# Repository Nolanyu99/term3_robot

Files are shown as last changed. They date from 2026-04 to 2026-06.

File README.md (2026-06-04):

# Term 3 Autonomous Robot

This repository contains the software, documentation, diagrams, and testing evidence for our Term 3 robotics challenge robot.

The final integrated robot software is an Arduino GIGA R1 WiFi project. It combines line following, IMU-based turning, RFID reading, MQTT/server communication, ultrasonic wall following, obstacle avoidance, arena pathfinding, return-to-base logic, emergency stop behaviour, revive behaviour, and seed dispensing.

---

## Final Viva/Test Run Version

The final code version used for the viva/test run is:

```text
Jason_combined_code/
```

The main file for the final integrated version is:

```text
Jason_combined_code/Main.ino
```

This folder is treated as the final assessed software version for the viva/test run.

Important note:

```text
All `.ino` files inside Jason_combined_code/ are part of the same Arduino sketch.
Do not upload Main.ino alone without the other tabs/files in the same folder.
```

---

## Final Code Folder Contents

| File | Purpose |
| --- | --- |
| `Main.ino` | Main integrated sketch. Defines configuration values, mission phases, global states, hardware pin assignments, tunnel logic, setup routine, calibration sequence, serial commands, stop/revive button handling, and the main mission state machine. |
| `ArenaTypes.h` | Shared type definitions used by the arena and revive logic, including `ArenaPoint`, `ArenaHeading`, `RFIDLocation`, and `Test8ReviveTarget`. |
| `ArenaPathfinding.ino` | Arena navigation and path planning. Uses an 11x11 planning grid around the 9x9 playable arena, decodes the 21-byte server map, uses weighted Dijkstra pathfinding, updates pose from RFID/server replies, marks temporary obstacles, and drives cell-by-cell toward a target. |
| `Messages.ino` | Non-blocking WiFi/MQTT communication layer. Handles WiFi reconnects, MQTT reconnects, topic building, incoming messages, map updates, fertility/location replies, revive broadcasts, emergency/disable messages, heartbeat/register messages, and server requests such as `isFertile`, `getMap`, `openAirlock`, and `reviveRequest`. |
| `IMU.ino` | IMU setup and gyro handling. Selects the best I2C bus, detects ADXL345, ITG320x, HMC5883L/QMC5883L, and BMP280, calibrates gyro Z-axis bias, integrates turn angle, and prints IMU status. |
| `LineSensors.ino` | 9-channel RC/QTR line sensor reading and calibration. Handles line detection, line position estimation, junction classification, line following, intersection crossing, gap recovery, and lost-line recovery. |
| `MotorEncoders.ino` | Motor and encoder support. Handles left/right encoder interrupts, encoder reads, Motoron setup, motor speed commands, stop commands, forward driving, proportional line-following motor correction, and centring after RFID/IR detection. |
| `ObstacleAvoid.ino` | Obstacle swerve state machine. Uses the forward ultrasonic sensor, line following without automatic junction turns, RFID-based junction detection, and scripted right/left turn sequence to move around an obstacle and return to the original trajectory. |
| `RFID.ino` | RFID reader setup and basic tag handling. Checks the RFID reader on I2C address `0x28`, validates firmware version, initialises the reader without soft reset, prints UID values, and triggers planting when a tag is detected in the simple RFID flow. |
| `RFIDServerTest.ino` | Manual and autonomous RFID/server helper. Provides `tryScanRFIDOnce()`, `scanRFIDAndQueryServer()`, and `runRFIDServerTest()`. The serial command `9` uses this to scan an RFID tag, send `isFertile`, wait for a server reply, and print UID, fertility, and x/y position. |
| `RobotBehaviour.ino` | Higher-level helper functions. Provides `plant()`, stop-input checking during blocking tests, and RFID scanning for test routines. Some older scripted test flows were removed because the arena pathfinder and server-based planting logic replaced them. |
| `Servos.ino` | Seed dispenser servo control. Converts angles to pulse widths, manually services servo pulses, closes both gates, and runs the upper/lower gate sequence to dispense one seed. |
| `Test8.ino` | Revive mission logic. Stores revive target broadcasts, selects a target, approaches using the forward ultrasonic sensor and line sensors if available, holds revive for 5 seconds, sends a revive request, then reverses until an RFID tag is found. |
| `Turning.ino` | IMU-based turning functions. Provides left/right 90-degree and 180-degree turns using gyro angle integration and line reacquisition, plus angle-only turning with timeout and stop-input checking. |
| `LEDs.ino` | RGB LED helper functions for red, green, yellow, blue, and flashing red status indication. |
| `Printing.ino` | Serial debug output. Prints line-following state, junction type, line position, motor commands, calibrated sensor values, IMU status, encoder counts, and calibration data. |

---

## Repository Structure

```text
term3_robot/
├── Jason_combined_code/       Final viva/test run Arduino sketch
├── Jason_wall_following_main/ Earlier wall-following version
├── Main/                      Earlier or alternative main code
├── Programming_Viva/          Earlier viva/programming modules
├── Test3/                     Older test code
├── Test8/                     Older or separate Test 8 code
├── Old/                       Archived code and older versions
├── cad/                       Mechanical CAD files and exports
├── docs/                      Documentation, planning material, datasheets, and test logs
├── include/                   Header files and shared definitions
├── src/                       PlatformIO source files and earlier application structure
├── platformio.ini             PlatformIO build configuration
├── RacetrackLineFollower.ino  Earlier line-following test code
└── README.md                  Repository guide
```

Only `Jason_combined_code/` should be treated as the final viva/test run version.

Other folders are kept for reference, diagnostics, earlier prototypes, or development history.

---

## Hardware Platform

The final code is designed for an Arduino GIGA R1 WiFi based differential-drive robot.

| Component | Purpose |
| --- | --- |
| Arduino GIGA R1 WiFi | Main microcontroller |
| Motoron motor controller | Controls the left and right drive motors |
| DC motors with encoders | Differential-drive movement and encoder feedback |
| 9-channel RC/QTR line sensor array | Line following, line recovery, and junction detection |
| IMU / gyro | Turn-angle estimation and IMU-based turning |
| RFID reader | Reads arena/base RFID tags |
| Forward ultrasonic sensor | Gate detection, obstacle detection, and revive approach distance |
| Side ultrasonic sensor | Tunnel wall-following distance measurement |
| Upper and lower servos | Seed dispenser gate mechanism |
| RGB LED | Robot status indication |
| Mechanical stop button | Pause / kill-switch behaviour |
| Revive button | Revive/contact trigger behaviour |
| WiFi/MQTT server link | Map, fertility, airlock, heartbeat, emergency, and revive communication |

---

## Important Pin and Address Configuration

The final configuration is defined mainly in `Main.ino`.

| Item | Configuration |
| --- | --- |
| Top RGB LED red | Pin `39` |
| Top RGB LED green | Pin `35` |
| Top RGB LED blue | Pin `37` |
| Mechanical stop button | Pin `33`, active low |
| Revive button | Pin `13`, active low |
| Line sensor pins | `2, 3, 4, 5, 8, 9, 10, 11, 12` |
| Left encoder | `A = 28`, `B = 26` |
| Right encoder | `A = 22`, `B = 24` |
| RFID reader | I2C address `0x28`, on `Wire1` |
| Motoron controller | I2C address `0x10`, on `Wire1` |
| Upper seed servo | Pin `36` |
| Lower seed servo | Pin `38` |
| Forward ultrasonic trigger/echo | Trigger `52`, echo `53` |
| Side ultrasonic trigger/echo | Trigger `47`, echo `46` |
| Serial baud rate | `115200` |

---

## Required Libraries

The final Arduino code uses these main libraries:

```cpp
#include <Arduino.h>
#include <Wire.h>
#include <Motoron.h>
#include <math.h>
#include <MFRC522_I2C.h>
#include "ArenaTypes.h"
```

The messaging layer also uses WiFi/MQTT-related Arduino networking functionality.

Before compiling, make sure the following are available in Arduino IDE or PlatformIO:

| Library / Dependency | Purpose |
| --- | --- |
| Arduino GIGA R1 board package | Arduino GIGA R1 WiFi support |
| `Wire` | I2C communication |
| `Motoron` | Motoron motor controller communication |
| `MFRC522_I2C` | RFID reader communication over I2C |
| Arduino WiFi / MQTT support | Server communication in `Messages.ino` |
| Arduino core libraries | General Arduino functions |

---

## Setup Steps

### 1. Clone or Download the Repository

```bash
git clone <repository-url>
```

Open the repository folder on your computer.

---

### 2. Open the Final Code

Open this file in Arduino IDE:

```text
Jason_combined_code/Main.ino
```

Arduino IDE should automatically load the other `.ino` files in `Jason_combined_code/` as tabs.

The final code depends on the full folder:

```text
Jason_combined_code/
```

Do not move `Main.ino` out of this folder unless all related `.ino` files and `ArenaTypes.h` are moved with it.

---

### 3. Select Board and Port

In Arduino IDE:

```text
Board: Arduino GIGA R1 WiFi
Port: Select the connected Arduino port
```

Use the M7 core if the IDE asks for the target core.

---

### 4. Install Required Libraries

Install the required external libraries through Arduino Library Manager or manually:

```text
Motoron
MFRC522_I2C
```

Also make sure the Arduino GIGA R1 WiFi board package and WiFi/MQTT dependencies are installed.

---

### 5. Check WiFi and Server Settings

The final code contains WiFi and MQTT/server settings for the robotics challenge environment.

Before uploading, check:

```text
WiFi SSID
WiFi password
MQTT broker address
Team ID
Board ID
Server board ID
Airlock/server message format
```

Security warning:

```text
Do not leave real WiFi credentials in a public GitHub repository.
```

If the repository is public, replace real credentials with placeholders, for example:

```cpp
constexpr const char* WIFI_SSID = "YOUR_WIFI_SSID";
constexpr const char* WIFI_PASSWORD = "YOUR_WIFI_PASSWORD";
```

Then document the real credentials privately for the team.

---

### 6. Upload the Code

Connect the Arduino GIGA R1 to the computer with a USB cable.

In Arduino IDE:

```text
Click Upload
```

After uploading, open Serial Monitor at:

```text
115200 baud
```

---

## How to Run the Robot

1. Place the robot at the correct start position.
2. Turn on the robot power system.
3. Connect the Arduino GIGA R1 to the computer if Serial Monitor is needed.
4. Upload the final code from `Jason_combined_code/`.
5. Open Serial Monitor at `115200`.
6. During startup, the robot runs calibration:

   * IR line sensor calibration
   * IMU stillness wait
   * Gyro Z-axis bias calibration
7. After calibration, the robot enters the mission state machine.
8. The default mission phase in the final code starts from `BaseToGate`.
9. The robot then follows the configured mission logic:

   * base line following
   * RFID handling
   * tunnel entry
   * wall following
   * arena behaviour
   * obstacle avoidance fallback
   * pathfinding if an arena goal is set
   * return-to-base if commanded
   * revive behaviour if commanded
   * seed dispensing when planting is triggered

---

## Serial Controls

The final integrated code includes serial commands for testing and selecting behaviours.

| Command | Action |
| --- | --- |
| `0` | Toggle running / paused state |
| `9` | Run RFID server test: scan one tag, send `isFertile`, and print UID/fertility/x/y |
| `8` | Reset and select the obstacle avoidance sequence |
| `4` | Trigger return-to-base sequence through Tunnel A |
| `7` | Run Test 8 / revive mission |
| `x` or `X` | Stop during some blocking test routines |

---

## Main Software Overview

The final version is organised around `Main.ino`, which initialises hardware, runs calibration, handles serial/buttons, and dispatches behaviours through a mission-level state machine.

```mermaid
flowchart TD
    A[Power on / reset] --> B[Serial start at 115200]
    B --> C[Initialise Motoron]
    C --> D[Initialise IMU]
    D --> E[Initialise encoders]
    E --> F[Initialise LED and buttons]
    F --> G[Initialise RFID]
    G --> H[Initialise servos]
    H --> I[Initialise tunnel logic]
    I --> J[Initialise tunnel return logic]
    J --> K[Initialise obstacle avoidance]
    K --> L[Initialise WiFi/MQTT messages]
    L --> M[IR calibration]
    M --> N[IMU stillness wait]
    N --> O[Gyro Z bias calibration]
    O --> P[Robot ready]
    P --> Q[Mission state machine]
```

---

## Mission State Machine

The main mission phases are:

```text
BaseToGate
Tunnel
Arena
ArenaToEntryGate
TunnelReturn
BaseReturnToParking
```

```mermaid
flowchart TD
    A[Robot Ready] --> B{Mission Phase}

    B --> C[BaseToGate]
    B --> D[Tunnel]
    B --> E[Arena]
    B --> F[ArenaToEntryGate]
    B --> G[TunnelReturn]
    B --> H[BaseReturnToParking]

    C --> C1[Handle RFID]
    C --> C2[Follow base line]
    C --> C3[Detect base gate with forward ultrasonic]
    C3 --> D

    D --> D1[Wait at base gate]
    D1 --> D2[Drive into tunnel]
    D2 --> D3[Wall follow]
    D3 --> D4[Wait at exit gate]
    D4 --> D5[Pass exit gate]
    D5 --> E

    E --> E1{Arena goal available?}
    E1 -->|Yes| E2[Arena pathfinding]
    E1 -->|No| E3[Obstacle avoidance swerve]

    F --> G
    G --> G1[Pathfind to Tunnel A doorway]
    G1 --> G2[Request outer door]
    G2 --> G3[Drive into airlock]
    G3 --> G4[Wall follow return tunnel]
    G4 --> G5[Request inner door]
    G5 --> H

    H --> H1[Parking line-follow placeholder]
```

---

## Sensor and Actuator Software Architecture

```mermaid
flowchart TD
    SENSORS[Sensor Inputs] --> MAIN[Main.ino Mission Logic]

    IR[9-channel IR/QTR line sensors] --> SENSORS
    IMU[IMU / Gyro] --> SENSORS
    RFID[RFID Reader] --> SENSORS
    USF[Forward Ultrasonic Sensor] --> SENSORS
    USS[Side Ultrasonic Sensor] --> SENSORS
    ENC[Wheel Encoders] --> SENSORS
    BUTTONS[Stop and Revive Buttons] --> SENSORS
    MQTT[WiFi/MQTT Server Messages] --> MAIN

    MAIN --> LINE[Line Following]
    MAIN --> TUNNEL[Tunnel / Wall Following]
    MAIN --> PATH[Arena Pathfinding]
    MAIN --> AVOID[Obstacle Avoidance]
    MAIN --> RETURN[Return-to-Base]
    MAIN --> REVIVE[Test 8 Revive]
    MAIN --> PLANT[Seed Planting]

    LINE --> MOTORS[Motoron Motor Control]
    TUNNEL --> MOTORS
    PATH --> MOTORS
    AVOID --> MOTORS
    RETURN --> MOTORS
    REVIVE --> MOTORS

    PLANT --> SERVOS[Upper and Lower Servos]
    MAIN --> LED[RGB LED Status]
```

---

## Startup and Calibration Flow

```mermaid
flowchart TD
    A[Power on / reset] --> B[Initialise hardware]
    B --> C[Blue LED: IR calibration]
    C --> D[Move sensors over floor and line for 5 seconds]
    D --> E[Print min/max calibration values]
    E --> F[Yellow LED: keep robot flat and still]
    F --> G[Wait for still IMU period]
    G --> H[Calibrate gyro Z-axis bias]
    H --> I[Robot ready]
```

Calibration sequence:

| Stage | Description |
| --- | --- |
| IR calibration | Move the line sensor array over both floor and line for around 5 seconds. |
| IMU stillness wait | Keep the robot flat and still when the LED is yellow. |
| Gyro bias calibration | The robot samples gyro Z-axis bias and uses it for turn-angle correction. |
| Ready | The robot enters the mission state machine after calibration finishes. |

---

## Line Following Flow

```mermaid
flowchart TD
    A[Read RC discharge times from 9 sensors] --> B[Update calibrated values]
    B --> C[Check whether line is found]

    C -->|No| D[Enter line gap state]
    D --> E[Drive forward briefly]
    E --> F[Lost-line recovery using last known side]
    F --> A

    C -->|Yes| G[Estimate weighted line position]
    G --> H[Calculate error from centre]
    H --> I[Apply proportional motor correction]
    I --> A

    C -->|Yes| J[Detect junction type]
    J --> K{Special junction?}
    K -->|No| G
    K -->|Left turn| L[Centre after IR then turn left]
    K -->|Right turn| M[Centre after IR then turn right]
    K -->|T or wide intersection| N[Centre after IR then turn right]
    L --> A
    M --> A
    N --> A
```

The line-following logic includes:

```text
Line detection threshold with hysteresis
Weighted line position estimation
Junction classification
Line gap recovery
Lost-line recovery
Proportional steering control
Turn recovery memory
```

---

## IMU Turning Flow

```mermaid
flowchart TD
    A[Start turn command] --> B{Motoron ready?}
    B -->|No| C[Abort turn]
    B -->|Yes| D{Gyro ready?}
    D -->|No| C
    D -->|Yes| E[Reset turn angle]

    E --> F[Spin left or right]
    F --> G[Integrate gyro Z angle]
    G --> H{Ignore-line angle passed?}
    H -->|No| I{Max angle or timeout?}
    H -->|Yes| J{Line detected during turn?}

    J -->|Yes| K[Stop, mark line found, return success]
    J -->|No| I

    I -->|No| F
    I -->|Timeout or max angle| L[Stop and enter lost-line recovery]
```

Turning functions:

```text
turnLeft90WithLines()
turnRight90WithLines()
turnLeft180WithLines()
turnRight180WithLines()
turnAngleOnly()
```

---

## Tunnel / Wall Following Flow

```mermaid
flowchart TD
    A[WaitAtBaseGate] --> B{Forward distance > base door open threshold?}
    B -->|No| A
    B -->|Yes| C[DrivingIntoTunnel]

    C --> D{Minimum encoder distance travelled?}
    D -->|No| C
    D -->|Yes| E{Side wall detected or timeout?}

    E -->|No| C
    E -->|Yes| F[WallFollow]

    F --> G{Exit gate detected ahead?}
    G -->|No| F
    G -->|Yes| H[WaitAtExitGate]

    H --> I{Exit gate opened?}
    I -->|No| H
    I -->|Yes| J[PassingExitGate]

    J --> K{Through exit gate?}
    K -->|No| J
    K -->|Yes| L[Enter Arena phase]
```

The wall-following controller uses the side ultrasonic sensor and a proportional correction:

```text
error = side_distance - target_side_distance
correction = WALL_KP * error
left_speed = base_speed - correction
right_speed = base_speed + correction
```

---

## Obstacle Avoidance Flow

`ObstacleAvoid.ino` implements a scripted swerve sequence around an obstacle.

```mermaid
flowchart TD
    A[LineFollow] --> B[Follow line without automatic junction turns]
    B --> C{Obstacle ahead by ultrasonic?}

    C -->|No| B
    C -->|Yes| D[ApproachObstacle]

    D --> E[Continue line following until RFID junction]
    E --> F[TurnRight]
    F --> G[GoStraightUntilJunc1]

    G --> H{Obstacle cleared and RFID junction reached?}
    H -->|No| G
    H -->|Yes| I[TurnLeft1]

    I --> J[GoStraightUntilJunc2]
    J --> K{Obstacle cleared and RFID junction reached?}
    K -->|No| J
    K -->|Yes| L[TurnLeft2]

    L --> M[GoStraightUntilJunc3]
    M --> N{RFID junction reached?}
    N -->|No| M
    N -->|Yes| O[Done]

    O --> P[Stop motors and reset swerve state]
```

This behaviour relies on:

```text
Forward ultrasonic obstacle detection
RFID tag detection at junctions
Line following with junction turns suppressed
IMU/line-based 90-degree turns
```

---

## Arena Pathfinding Flow

`ArenaPathfinding.ino` provides weighted navigation for the arena.

```mermaid
flowchart TD
    A[Request getMap from server] --> B[Decode 21-byte 9x9 map]
    B --> C[Store map in 11x11 planner grid]
    C --> D[Update pose using RFID and isFertile reply]
    D --> E{Pose known?}

    E -->|No| F[Wait for first known RFID pose]
    F --> D

    E -->|Yes| G[Run weighted Dijkstra to goal]
    G --> H{Path found?}

    H -->|No| I[Stop and report no path]
    H -->|Yes| J[Take next cell in path]

    J --> K{Obstacle ahead?}
    K -->|Yes| L[Temporarily block next cell]
    L --> G

    K -->|No| M[Turn toward next cell]
    M --> N[Drive one cell using line following]
    N --> O{RFID confirms pose?}

    O -->|Yes| P[Update pose from RFID/server]
    O -->|No| Q[Estimate pose by dead reckoning]

    P --> R{Goal reached?}
    Q --> R

    R -->|No| G
    R -->|Yes| S[Stop motors]
```

Map states:

```text
0 = unknown
1 = seeded
2 = fertile
3 = infertile
```

The pathfinder uses weighted costs so that explored cells and lower-y cells can be preferred, while unknown cells and temporary obstacles receive different costs.

---

## RFID and Server Flow

```mermaid
flowchart TD
    A[RFID tag detected] --> B[Convert UID to text]
    B --> C[Send isFertile request to server]
    C --> D[Wait for fertility/location reply]

    D --> E{Reply received?}
    E -->|No| F[Print no reply / fallback if available]
    E -->|Yes| G[Read x, y, and state]

    G --> H{State fertile?}
    H -->|Yes| I[Plant if mission logic requires it]
    H -->|No| J[Do not plant]

    G --> K[Update arena pose]
```

The `9` serial command runs a manual RFID/server diagnostic:

```text
Scan RFID tag
Send isFertile request
Wait for server reply
Print UID
Print server state
Print fertility
Print x/y coordinates
```

---

## Seed Dispensing Flow

```mermaid
flowchart TD
    A[Plant command] --> B[Close both gates]
    B --> C[Centre robot after RFID]
    C --> D[Stop motors]
    D --> E[Open upper servo gate]
    E --> F[Close upper servo gate]
    F --> G[Open lower servo gate]
    G --> H[Close lower servo gate]
    H --> I[Dispense cycle complete]
```

The dispenser uses two servos:

```text
Upper servo: controls seed loading gate
Lower servo: controls seed release gate
```

Servo pulses are manually serviced using `serviceServoPulses()` instead of relying on a standard Servo library.

---

## Return-to-Base Flow

```mermaid
flowchart TD
    A[Serial command 4 selected] --> B[Set mission phase to ArenaToEntryGate]
    B --> C[Pathfind to Tunnel A doorway cell]
    C --> D{Reached doorway?}

    D -->|No| E[Retry next tick]
    E --> C

    D -->|Yes| F[Request outer Tunnel A door]
    F --> G[Wait until forward ultrasonic says door opened]
    G --> H[Drive into airlock]
    H --> I[Detect side wall or timeout]
    I --> J[Wall follow return tunnel]
    J --> K[Reach inner door]
    K --> L[Request inner door]
    L --> M[Wait for inner door to open]
    M --> N[Pass inner door]
    N --> O[Enter base]
    O --> P[BaseReturnToParking]
```

Current limitation:

```text
BaseReturnToParking is still a placeholder and currently uses general line following.
```

---

## Test 8 / Revive Flow

`Test8.ino` implements a revive mission using server revive broadcasts, forward ultrasonic distance, line sensors, and the revive button.

```mermaid
flowchart TD
    A[Serial command 7 selected] --> B{Robot calibrated and running?}
    B -->|No| C[Print error and stop]
    B -->|Yes| D[Update pose from RFID if possible]

    D --> E[Select known revive target if available]
    E --> F[Approach object using forward ultrasonic sensor]

    F --> G{Within 10 cm?}
    G -->|No| F
    G -->|Yes| H[Slow approach]

    H --> I{Revive button pressed?}
    I -->|No| H
    I -->|Yes| J[Hold revive for 5 seconds]

    J --> K[Send revive request if target ID known]
    K --> L[Reverse until RFID tag is found]
    L --> M[Stop and show green LED]
```

Test 8 can still operate in a distance-sensor-only mode if no server revive target is known.

---

## Stop / Emergency Behaviour

The final code includes both physical and software stop handling.

```mermaid
flowchart TD
    A[Robot running] --> B{Stop button pressed?}
    B -->|No| C{Serial stop command?}
    C -->|No| D{Remote emergency/disable?}
    D -->|No| E[Continue mission]
    E --> A

    B -->|Yes| F[Toggle running state]
    C -->|Yes| G[Stop motors]
    D -->|Yes| G

    F --> H{Running enabled?}
    H -->|Yes| E
    H -->|No| G

    G --> I[Stop motors]
    I --> J[Flash red LED or print stop message]
```

Stop inputs are checked in the main loop and inside some blocking test routines such as turning, pathfinding, and revive behaviour.

---

## Testing and Calibration Evidence

Testing and calibration evidence is stored in:

```text
docs/test_logs/
├── final_viva_test_log.md

---

## Calibration Notes

The robot requires calibration before reliable operation.

Main calibration steps:

1. IR line sensors:

   * Move the sensor array over both the floor and the line during startup.
   * The calibration lasts around 5 seconds.
   * This improves line detection, line position estimation, and junction classification.

2. IMU gyro:

   * Place the robot flat and still when the LED is yellow.
   * The robot samples the gyro Z-axis bias.
   * This improves IMU-based turning.

3. Motor and encoder direction:

   * Test each motor direction after wiring changes.
   * Test encoder direction before using encoder-based centring or tunnel movement.
   * Keep the robot wheels raised during first motor tests.

4. Ultrasonic sensors:

   * Check forward and side distance readings before tunnel and obstacle tests.
   * Confirm that distance thresholds match the actual arena setup.

5. RFID reader:

   * Confirm the reader is detected at I2C address `0x28`.
   * Confirm known tags can be read reliably.
   * Check tag distance and orientation.

6. Seed dispenser:

   * Test upper and lower servo angles before loading seeds.
   * Confirm only one seed is released per dispense cycle.

7. MQTT/server:

   * Confirm WiFi connects to the correct network.
   * Confirm MQTT messages can be sent and received.
   * Test `register`, `heartbeat`, `isFertile`, `getMap`, `openAirlock`, and revive messages separately if possible.

---

## Known Limitations

The final integrated code is a combined competition build. Some behaviours are more mature than others.

Known limitations:

* Real WiFi credentials should not be left in a public repository.
* WiFi/MQTT communication is non-blocking, so the robot can continue moving when WiFi is unavailable, but server-dependent behaviours may fail or fall back.
* `BaseReturnToParking` is currently a placeholder and uses general line following rather than a fully developed parking routine.
* Arena pathfinding depends on having a known RFID pose. If no RFID pose is obtained, the robot may not be able to pathfind.
* If RFID confirmation is not received during arena movement, pose may be estimated by dead reckoning, which can accumulate error.
* The arena pathfinder uses a simplified 11x11 planning grid around the 9x9 playable arena and assumes the server map format matches the expected 21-byte packed map.
* Temporary obstacle handling depends on the forward ultrasonic sensor; angled surfaces or noisy readings may cause false obstacle detection.
* The obstacle avoidance sequence is scripted and assumes the obstacle and junction layout match the tested path.
* Tunnel wall following assumes the wall is on the expected side. The return tunnel code notes that the wall-following direction may need mirroring if the wall is on the opposite side.
* Line following can become unstable if lighting changes, the sensor height changes, or IR calibration is poor.
* IMU turning depends on successful gyro detection and still calibration. Drift or vibration can reduce turn accuracy.
* RFID detection depends on tag position, reader distance, and reader orientation.
* The seed dispenser uses manually generated servo pulses, so long blocking code sections must continue calling `serviceServoPulses()`.
* Some routines are blocking for several seconds, although many of them still service messages, servos, and stop inputs during the blocking period.
* The revive mission can run in distance-sensor-only mode, but full revive target selection depends on receiving valid server revive broadcasts.
* Some older folders in the repository are archived prototypes and should not be treated as the final assessed version.

---

## Final Submission Checklist

The GitHub repository should include:

* [x] Latest code version
* [x] Final viva/test run code clearly identified as `Jason_combined_code/`
* [x] README explaining repository structure
* [x] README explaining every final code file
* [x] Required libraries listed
* [x] Setup and upload instructions
* [x] Software overview diagram
* [x] Flowcharts for key behaviours
* [x] Testing/calibration evidence section
* [x] Known limitations section
* [x] Notes on what worked and what may still fail

---

## Important Note for Assessors

The final assessed code is located in:

```text
Jason_combined_code/
```

Please use this folder as the final viva/test run version.

Other folders such as:

```text
Old/
Test3/
Test8/
Programming_Viva/
Jason_wall_following_main/
src/
Main/
```

are kept for reference, diagnostics, earlier prototypes, or development history.

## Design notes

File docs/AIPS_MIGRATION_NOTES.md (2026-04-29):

# AIPS notes for term3_robot

Useful pieces imported/adapted from `AIPS`:

- WiFi/UDP bring-up pattern: scan, connect, open UDP port, reply to sender.
- PID controller: compact target/gain/integral-limit loop for motor velocity.
- Cooperative task scheduler: small periodic task runner for motor, UDP, status loops.
- Encoder velocity calculation: interrupt count delta -> rad/s with low-pass filtering.
- Manual DFU upload workaround for Arduino GIGA R1 on this Windows machine.

Pieces intentionally not copied directly:

- `Modulino` peripherals: UNO R4-specific and not needed until hardware is chosen.
- `Motoron` driver binding: useful if the robot uses Pololu Motoron, but the starter uses generic PWM+DIR pins because `term3_robot` does not yet define a motor driver.
- Master/slave I2C split: AIPS is a two-board robot; this starter begins as one GIGA project.
- OLED, LiDAR, QTR sensor code: keep these as references in AIPS until the new robot hardware layout is fixed.

Next hardware decisions:

1. Pick the motor driver board and update `EncoderMotor::write_power()` if it is not PWM+DIR.
2. Update `include/robot_config.hpp` with real pins and WiFi credentials.
3. If you use the Pololu Motoron, copy the AIPS `motor.hpp/.cpp` style instead of this generic motor class.
4. Add packet definitions for your controller app once command format is known.

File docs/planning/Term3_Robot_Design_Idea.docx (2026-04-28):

Proposed Robot Design

Overall idea: The robot should be easy to CAD, manufacture, assemble, test, and modify within the available lab time. The design is based on a simple two-layer acrylic robot structure, a bit similar to my Term 2 group robot

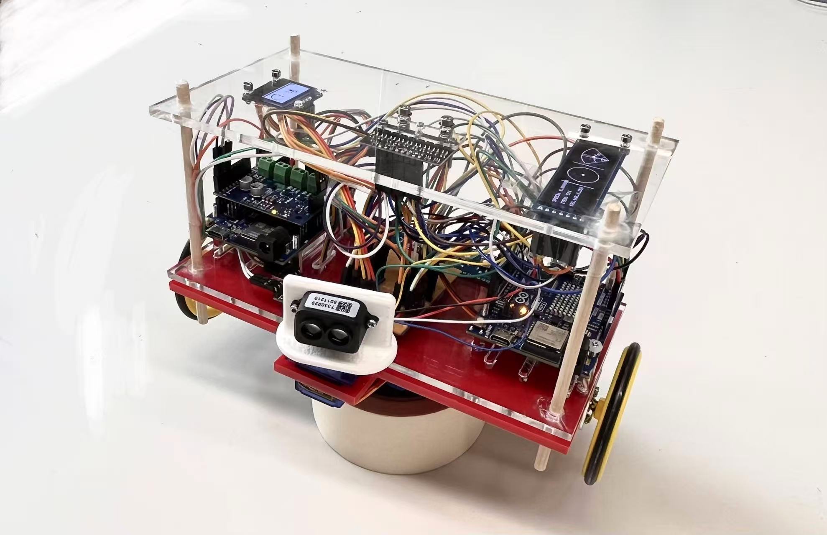
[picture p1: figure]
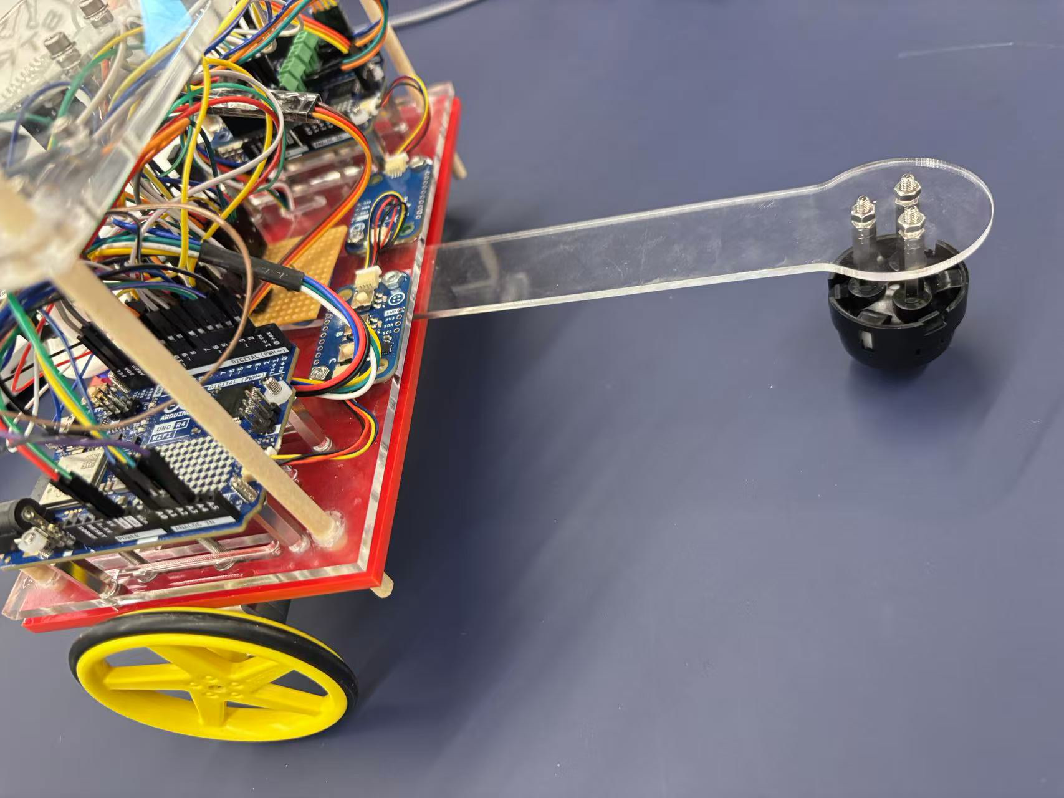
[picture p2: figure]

# Quick Design Summary

Subsystem | Proposed design
Drivetrain | Two-wheel differential drive + rear caster wheel / ball caster
Chassis | Two-layer laser-cut acrylic chassis with standoffs
Controller | Arduino GIGA R1 WiFi on the upper deck
Motor driver | Motoron M3S550 motor driver board on the upper deck
Line following | Front-bottom reflectance sensor array, height-adjustable
Distance sensing | Front ToF distance sensor; optional side ToF if time allows
RFID | Bottom-mounted RFID reader close to the seed outlet
Planting | Low-profile angled 5-seed hopper + SG90 servo gate
Reviving | Wide front bumper button + top red/green LED
Safety | Top hardware kill switch + WiFi software kill switch
Target size | Approximately 190 mm x 170 mm x 130-140 mm

# 1. Drivetrain

I think we should make the robot a two-wheel differential-drive car, with one rear caster wheel or ball caster for support. This would be similar to the robot my group built in Term 2.

The reason for this choice is that it is simple and realistic for us to build. It is easy to control, has a small turning radius, saves material, and works well for line following. It also means we do not need a complicated steering mechanism. From the software side, we only need to control the speed of the left and right motors.

# 2. Chassis Design

I think we should use a two-layer acrylic chassis.

The lower layer can hold the motors, battery, RFID reader, reflectance line sensor, seed outlet, and some of the wiring.

The upper layer can hold the Arduino GIGA, Motoron motor driver board, hardware kill switch, LED, and the support structure for the planting mechanism.

This layout should make the robot easier to manufacture, assemble, debug, and modify later.

# 3. Electronics Placement

The Arduino GIGA R1 WiFi and the Motoron M3S550 should be mounted on the upper acrylic plate.(not sure because I don’t know the exact weight)

The battery should be mounted on the lower layer and placed as close to the centre of the robot as possible.

The reason is that the Arduino and Motoron need to be easy to access for wiring, debugging, and replacement. The battery is relatively heavy, so placing it low and central will lower the centre of gravity. This should make the robot more stable when turning, going through the tunnel, or moving on small ramps.

# 4. Reflectance Line Sensor

The reflectance sensor array should be mounted at the front bottom of the robot, as close to the ground as possible.

The suggested height is around 3-8 mm above the ground.

Its job is to detect the black lines on the floor so the robot can follow them.

The reason for placing it at the front is that the robot can detect the line earlier and correct its direction before it drifts too much. If the sensor is too far back, the robot may already be off the line before it reacts.

From my Term 2 experience, this kind of sensor can be unreliable if the height is not correct. So I think the sensor bracket should be height-adjustable, because the reflectance sensor is sensitive to both distance from the ground and lighting conditions. We may need to fine-tune it during testing.

# 5. Distance Sensor

I think we should add a ToF distance sensor at the front of the robot.

It should face forward and be placed above the reflectance sensor array.

Its purpose is to detect the distance to walls, detect the airlock door position, prevent the robot from crashing, detect obstacles or other robots in front, and help with emergency return if we need to follow another robot without hitting it.

If we have time, we could also add a side ToF sensor for wall following. However, the front ToF sensor should be the priority, because it is more directly useful for stopping and obstacle detection.

For obstacle avoidance, I have not fully decided on the final strategy yet, but using a ToF distance sensor seems like the most realistic option.

# 6. RFID Reader

The RFID reader should be mounted underneath the robot, near the front-middle area, and as close as possible to the seed outlet.

The reason is that each planting hole in the main arena has an RFID tag underneath it. When the robot reads a tag, it sends the tag ID to the server through WiFi and asks whether that location is fertile or infertile. If the location is fertile, the robot plants one seed.

If the RFID reader and the seed outlet are far apart, the robot would need to move again after reading the tag, which could introduce positioning errors. If we keep the RFID reader and seed outlet close together, the robot can almost plant in place after reading a valid tag, which should improve accuracy.

# 7. Planting Mechanism

For the planting mechanism, I suggest using a low-profile angled seed hopper(because height limit is 15cm), an SG90 servo gate, and a bottom seed outlet.

The seed diameter is about 12.7 mm, so the internal diameter or width of the hopper should be around 14-16 mm.

The hopper should hold up to 5 seeds. The seeds can sit in an angled tube or channel, with the lowest seed near the outlet. When the robot needs to plant, the SG90 servo opens a small gate, releases one seed, and then closes again.

The reason for using an angled hopper is that it is lower than a vertical tube, so it is less likely to exceed the 15 cm height limit. It also keeps the centre of gravity lower, which makes the robot more stable. The structure is simple, easy to 3D print or make with a tube, and the SG90 servo is cheap, common, and easy to control with Arduino. We only need two positions: closed(0 degree of servo) and open(90 degree of servo).

The main risk is releasing more than one seed at a time. To avoid this, the outlet should ideally have a small single-seed pocket, so only one seed can reach the outlet at a time.

# 8. Seed Outlet Position

The seed outlet should be on the bottom of the robot and close to the RFID reader.

The reason is that the planting position depends on the RFID tag. If the RFID reader detects the correct tag but the seed outlet is far away, the seed may miss the hole. Keeping the RFID reader and seed outlet close together reduces alignment error and should improve planting accuracy.

# 9. Revive Mechanism

The robot needs a mechanical revive button or bumper at the front.

I suggest using a wider front bumper plate with a push button or micro switch behind it.

When another robot touches or pushes the front bumper, the button will be pressed, and the top LED should change from red to green.

The reason is that a small button may be difficult for another robot to press accurately. A wider bumper gives a larger contact area and makes the revive mechanism easier to trigger during the actual challenge.

# 10. Top LED

We need a red/green LED indicator on the top of the robot.

The default state should be red. After the front revive button is pressed, it should turn green.

This makes it easy for people and the judges to see whether the robot has been revived. The LED should be placed on top so it is visible, but we still need to make sure the total height stays under 15 cm.

# 11. Kill Switches

The robot needs two kill switches: a top hardware kill switch and a WiFi software kill switch.

The hardware kill switch should be on the top of the robot, ideally as a clear red button. It is for safety, so someone can stop the robot quickly.

The software kill switch will be implemented through WiFi and code. If the server sends a stop command, the Arduino should immediately stop the motors.

So mechanically, we need to leave space and mounting holes for the top hardware kill switch. In software, we need to include the WiFi kill switch in the robot state machine.

# 12. Overall Layout Summary

The robot should include the following main elements:

- a two-layer acrylic chassis
- left and right drive wheels
- one rear caster wheel or ball caster
- Arduino GIGA R1 WiFi as the main controller
- Motoron M3S550 motor driver for motor control
- front-bottom reflectance sensor array for line following
- front ToF distance sensor for wall distance and obstacle detection
- bottom RFID reader for identifying planting locations
- low-mounted battery compartment for better stability
- front revive button / bumper
- top red/green LED indicator
- top hardware kill switch
- simple angled seed hopper for up to 5 seeds
- SG90 servo gate to release one seed at a time
- bottom seed outlet close to the RFID reader

Target dimensions: approximately 190 mm x 170 mm x 130-140 mm. This keeps the robot safely under the maximum size limit of 20 x 20 x 15 cm.

# 13. Suggested Physical Layout

Front: revive bumper button, ToF distance sensor, reflectance sensor array.

Bottom / front-middle: RFID reader, seed outlet.

Middle: left and right motors, left and right drive wheels, low-mounted battery.

Upper layer: Arduino GIGA, Motoron M3S550, hardware kill switch, red/green LED, tidy wiring.

Rear or rear-side: low-profile angled seed hopper, SG90 servo gate.

Rear bottom: caster wheel or ball caster.

This is the image from gpt5.5, which is not accurate and there are some mistakes. You guys can have a look because the words are abstract, I think image is better to understand.

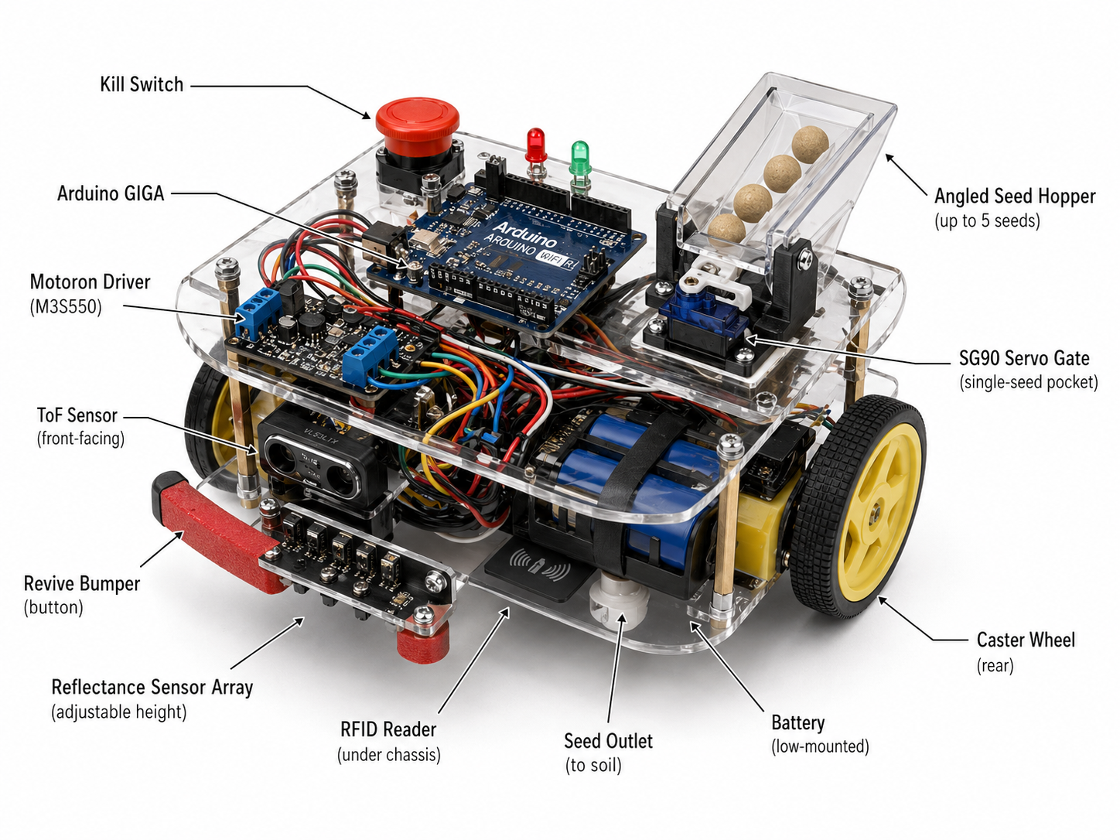
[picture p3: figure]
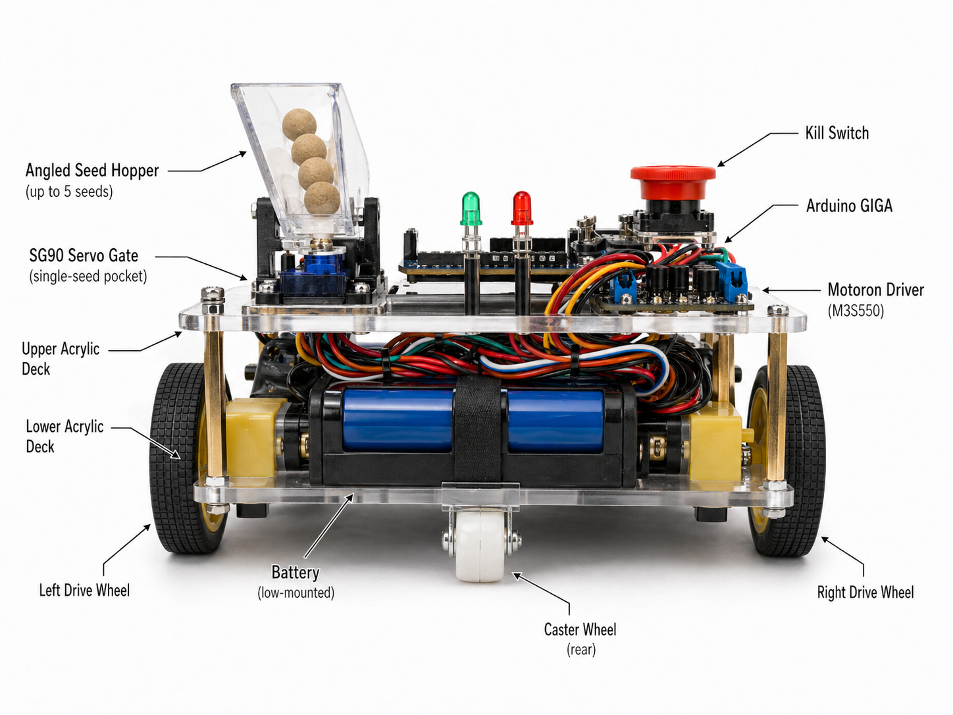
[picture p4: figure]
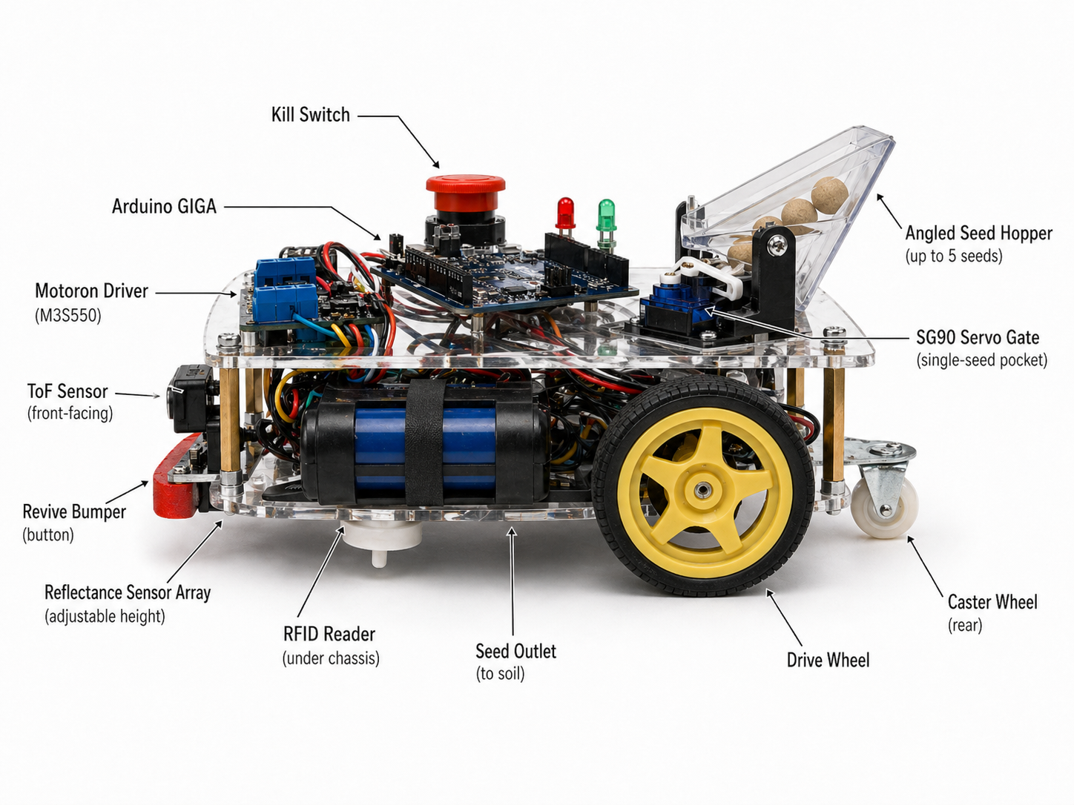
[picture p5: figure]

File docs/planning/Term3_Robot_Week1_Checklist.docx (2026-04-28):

Term 3 Robotics Challenge - Updated Week 1 Planning Pack

Checklist | Hardware List | Mounting Points | Revised Task Allocation | Week 1-3 Roadmap

This updated version fixes the main issues in the previous task split: Person 1 and Person 2 now have a clearer CAD/mechanism interface, Person 3 and Person 4 are explicitly paired for hardware testing, Week 1 goals are more realistic, and the plan is tightened because trial runs begin in Week 3.

# 1. Design Assumptions

- Robot concept: two-wheel differential-drive car with one rear caster wheel or ball caster, similar in complexity to our Term 2 robot.
- Chassis: two-layer laser-cut acrylic plate structure with standoffs/spacers and simple 3D-printed brackets.
- Target size: approximately 190 mm x 170 mm x 130-140 mm, safely below the 20 x 20 x 15 cm limit.
- Main objective for Week 1: not a complete robot, but a manufacturable first prototype design plus key module tests.
- Main objective before Week 3 trial run: basic integrated task flow, even if not fully optimised.

# 2. Robot Design Checklist

Requirement | Proposed solution | Priority / status
Maximum size: 20 x 20 x 15 cm | Target design: 190 x 170 x 130-140 mm | Must confirm in CAD
Hardware kill switch | Top-mounted red button, easy to press | Required
Software kill switch over WiFi | Implemented in Arduino state machine / communication logic | Required
Line detection | Front-bottom reflectance sensor array on adjustable bracket | Required
Wall/distance detection | Front ToF distance sensor; optional side ToF if time allows | Required
Battery power | Battery mounted low and central on lower deck | Required
No breadboard in finals | Week 1 testing can use jumper wires/breadboard; final must move to perfboard/soldered board/PCB | Important clarification
Tidy wiring | Cable routing slots, zip-tie holes, fixed electronics modules | Required
Planter / hopper up to 5 seeds | Low-profile angled seed hopper, 14-16 mm internal width/diameter | Required
Seed release | SG90 servo gate plus single-seed pocket to reduce double-release risk | Required
Front revive button | Wide front bumper plate with push button/micro switch behind it | Required
Top LED red/green | Red by default, green when revive bumper/button is pressed | Required

# 3. Hardware List

## 3.1 Provided / expected core hardware

Part | Purpose | Mounting location
Arduino GIGA R1 WiFi | Main controller, WiFi communication, sensor reading, servo control | Upper acrylic deck
Motoron M3S550 motor shield | Controls left and right drive motors | Upper acrylic deck, close to Arduino
Reflectance sensor array | Line following | Front-bottom adjustable bracket
RFID sensor / reader | Reads RFID tags under planting holes | Under chassis, close to seed outlet

## 3.2 Additional hardware likely needed

Part | Purpose | Notes
2 DC gear motors | Left/right differential drive | Must be compatible with Motoron and chosen battery voltage
2 drive wheels | Main movement | Approx. 60-70 mm diameter preferred
1 rear caster wheel / ball caster | Rear support | Keeps drivetrain simple and compact
Battery pack | Final power source | Mount low and central for stability
Front ToF distance sensor | Wall, obstacle, door detection | Front-facing priority
Optional side ToF sensor | Wall following | Add only if time allows
SG90 servo | Seed gate open/close | For one-seed release mechanism
Push button / micro switch | Revive trigger | Behind wide front bumper
Red/green LED or RGB LED | Revive status indicator | Top-mounted and visible
Hardware kill switch | Manual emergency stop | Top-mounted, easy to press
Acrylic sheets | Two-layer chassis | Laser cut in lab
Standoffs / spacers | Separate upper and lower decks | Nylon or metal; nylon is non-conductive
Screws / nuts / washers | Mounting all modules | M3 hardware recommended
Zip ties / cable clips | Cable management | Important for inspection
Perfboard / soldered board | Final wiring | Finals should not use breadboard

# 4. Mounting Points

## 4.1 Lower acrylic deck

Component | Mounting point needed | Notes
Left motor | Motor bracket holes | Align axle with left wheel
Right motor | Motor bracket holes | Align axle with right wheel
Rear caster / ball caster | 3-4 screw holes | At rear centre
Battery | Strap holes / bracket holes | Low and central
RFID reader | 2-4 screw holes or small bracket | Under chassis, close to seed outlet
Reflectance sensor array | Adjustable-height front bracket holes | Approx. 3-8 mm from ground
Seed outlet | Circular outlet hole | Close to RFID reader
Cable routing | Small slots / zip-tie holes | Avoid hanging wires

## 4.2 Upper acrylic deck

Component | Mounting point needed | Notes
Arduino GIGA R1 WiFi | 4 mounting holes | Keep USB access clear
Motoron M3S550 | 4 mounting holes | Close to Arduino and motor wires
Hardware kill switch | Large circular hole | Top, easy to press
Red/green LED | Small LED hole / bracket | Top visible position
Seed hopper support | Bracket mounting holes | Rear or rear-side, low-profile
SG90 servo bracket | Servo screw holes | Close to hopper outlet
Cable management | Zip-tie holes | Keep wiring fixed

## 4.3 Front section

Component | Mounting point needed | Notes
Revive bumper | Two side brackets | Wide enough for another robot to press
Push button / micro switch | Behind bumper | Must trigger reliably
Front ToF sensor | Small vertical bracket | Above line sensor
Reflectance sensor array | Low adjustable bracket | Must not block bumper

## 4.4 Rear / rear-side section

Component | Mounting point needed | Notes
Angled seed hopper | 3D-printed support bracket | Low-profile to stay under 15 cm
SG90 servo gate | Servo bracket | Needs reliable open/close positions
Single-seed pocket | Integrated with hopper/outlet | Prevents two seeds dropping at once

# 5. Revised Task Allocation for 4 People

This allocation is mainly for Week 1. The same roles can continue later, but the tasks should be updated after the first prototype and module tests. The most important correction is that CAD/mechanism and electronics/software are not fully independent: they must work through clear interfaces.

## Person 1: Main CAD / Chassis Integration

- Design the main two-layer acrylic chassis and overall component layout.
- Place motors, wheels, rear caster, battery, Arduino, Motoron, RFID reader, reflectance sensor, ToF sensor, hopper, servo, kill switch, and LED.
- Integrate Person 2's hopper / servo gate / revive bumper geometry into the full chassis CAD.
- Add mounting holes, standoff holes, zip-tie holes, and cable routing holes.
- Keep the robot under 20 x 20 x 15 cm.
- Export prototype DXF/STL files for laser cutting and 3D printing.

Deliverables: chassis CAD, upper/lower deck DXF files, mounting hole layout, size check drawing, first prototype export files.

## Person 2: Planting + Reviving Mechanism

- Design the angled hopper for up to 5 seeds.
- Design the SG90 servo gate and single-seed pocket.
- Design the bottom seed outlet.
- Design the front revive bumper and button/micro switch mounting.
- Provide exact dimensions and mounting hole requirements to Person 1.
- Support quick manual testing of seed flow and bumper/button triggering.

Deliverables: hopper CAD, servo gate CAD, revive bumper CAD, seed outlet design, mechanism test notes, mounting interface requirements for Person 1.

## Person 3: Electronics / Wiring

- Test Arduino GIGA upload.
- Wire Arduino, Motoron, motors, reflectance sensor array, RFID reader, ToF sensor, servo, LED, revive button, and kill switch.
- Create pin assignment table and wiring diagram.
- Plan battery power route and hardware kill switch wiring.
- Plan tidy cable management and the final perfboard/soldered board solution.
- Work directly with Person 4 during all module tests.

Deliverables: pin assignment table, wiring diagram, power plan, initial hardware test setup, cable management plan.

## Person 4: Software / Test Logging

- Write Arduino upload/blink test.
- Write motor test code.
- Write reflectance sensor reading/calibration code.
- Write RFID reader test code.
- Write ToF distance sensor test code.
- Write servo gate test code.
- Write button/LED test code.
- Record sensor readings, test results, and failure notes.
- Create only a basic state machine draft in Week 1; full integration comes later.

Deliverables: test code for each module, testing checklist, sensor calibration notes, initial state machine draft, test log.

# 6. Collaboration Interfaces

Interface | How to avoid conflict
Person 1 + Person 2 | Person 2 designs mechanisms; Person 1 integrates them into the main chassis CAD and final mounting layout.
Person 2 + Person 3 | Person 2 provides servo/button/LED mechanical locations; Person 3 checks cable reach, connector access, and power routing.
Person 3 + Person 4 | Person 3 wires hardware; Person 4 runs code and logs data. Tests must be done together.
Person 1 + Person 3 | Person 3 provides board sizes, connector access needs, battery dimensions, and cable routing requirements to Person 1.

# 7. 3-Day Week 1 Sprint Plan

Because trial runs begin in Week 3, Week 1 must produce a manufacturable prototype plan and start real module testing. The goal is not perfection; the goal is to expose problems early.

## Day 1: Finalise concept + start CAD + confirm Arduino upload

Area | Tasks | Minimum result
All team | Agree on final layout: two-wheel differential drive, two-layer acrylic chassis, angled hopper, front bumper, front ToF, bottom RFID. | Concept fixed; no major architecture changes after this unless a test fails badly.
CAD | Start chassis layout and component footprint placement. | Main dimensions and component blocks placed.
Mechanism | Sketch hopper, servo gate, single-seed pocket, and revive bumper. | Mechanism direction confirmed.
Electronics | Connect Arduino GIGA and test upload. | Arduino upload works.
Software | Prepare motor/IR/RFID/servo/button test code templates. | Test code framework ready.

## Day 2: First CAD version + priority module tests

Area | Tasks | Minimum result
CAD | Add mounting points, check size, integrate mechanism interfaces. | First chassis CAD mostly complete.
Mechanism | Complete first hopper/servo/bumper CAD and provide hole/interface dimensions. | Mechanism CAD first version ready.
Electronics + Software | Priority tests: Motoron + one motor, reflectance sensor black/white readings, servo movement. If time: RFID, ToF, button/LED. | At least 2-3 modules tested and logged.

Day 2 priority note: Do not over-promise every module. Must test at least motor or IR sensor plus one other key module. RFID, ToF, and button/LED are important, but can continue into Day 3 if wiring or library issues occur.

## Day 3: Export prototype files + record test results + Week 2 fix list

Area | Tasks | Minimum result
CAD | Export DXF/STL for first prototype manufacturing. Check dimensions and component clearances. | Prototype manufacturing files ready.
Mechanism | Finalise printable hopper/servo/bumper parts; check if hopper fits 5 x 12.7 mm seeds. | Mechanism files ready for prototype.
Electronics | Finish pin assignment, wiring diagram, power plan, and cable management plan. | Pin table and wiring plan ready.
Software | Record all test results, sensor readings, failures, and create basic state machine outline. | Test log and Week 2 software plan ready.

# 8. Week 2 and Week 3 Roadmap

Week | Main goal | Minimum target
Week 2 | Manufacture, assemble, and start integration. | First prototype assembled; motors can move; IR line following starts; RFID reader mounted/tested; servo seed gate tested on the robot; revive button + LED works.
Week 3 before trial run | Basic task flow, even if imperfect. | Robot can move along a line, read RFID, trigger seed release using a real or simulated server response, stop for obstacles, respond to kill/emergency logic, and produce a clear bug list after trial.

# 9. Main Risks and Controls

Risk | Control / mitigation
Reflectance sensor unreliable due to height or lighting | Use adjustable-height bracket; test black/white values early.
RFID reader cannot read reliably through chassis or at chosen height | Mount under chassis near ground; test read distance before finalising bottom plate.
Seed gate releases more than one seed | Use a single-seed pocket and test repeated releases.
CAD becomes too crowded | Keep target size below limit but leave service space; use two-layer layout.
Electronics/software testing blocked by wiring problems | Person 3 and Person 4 test together; maintain pin table.
Final wiring not allowed because of breadboard use | Use breadboard/jumpers only for Week 1 tests; plan perfboard/soldered board for final.
Week 3 trial run arrives before integration is ready | Focus Week 1 on manufacturable prototype and module tests; focus Week 2 on integration, not extra features.

# 10. End-of-Week-1 Minimum Success Criteria

- Final concept agreed.
- First chassis CAD layout completed and exportable for prototype manufacturing.
- Hopper and revive mechanism first version designed.
- Arduino upload confirmed.
- Motoron + at least one motor test started or completed.
- Reflectance sensor black/white reading test started or completed.
- Servo movement test completed.
- RFID reader test started if time and wiring allow.
- Pin assignment table completed.
- Wiring diagram first version completed.
- Week 2 manufacturing/debugging fix list written.

Term 3 Robotics Challenge - Updated Week 1 Planning Pack

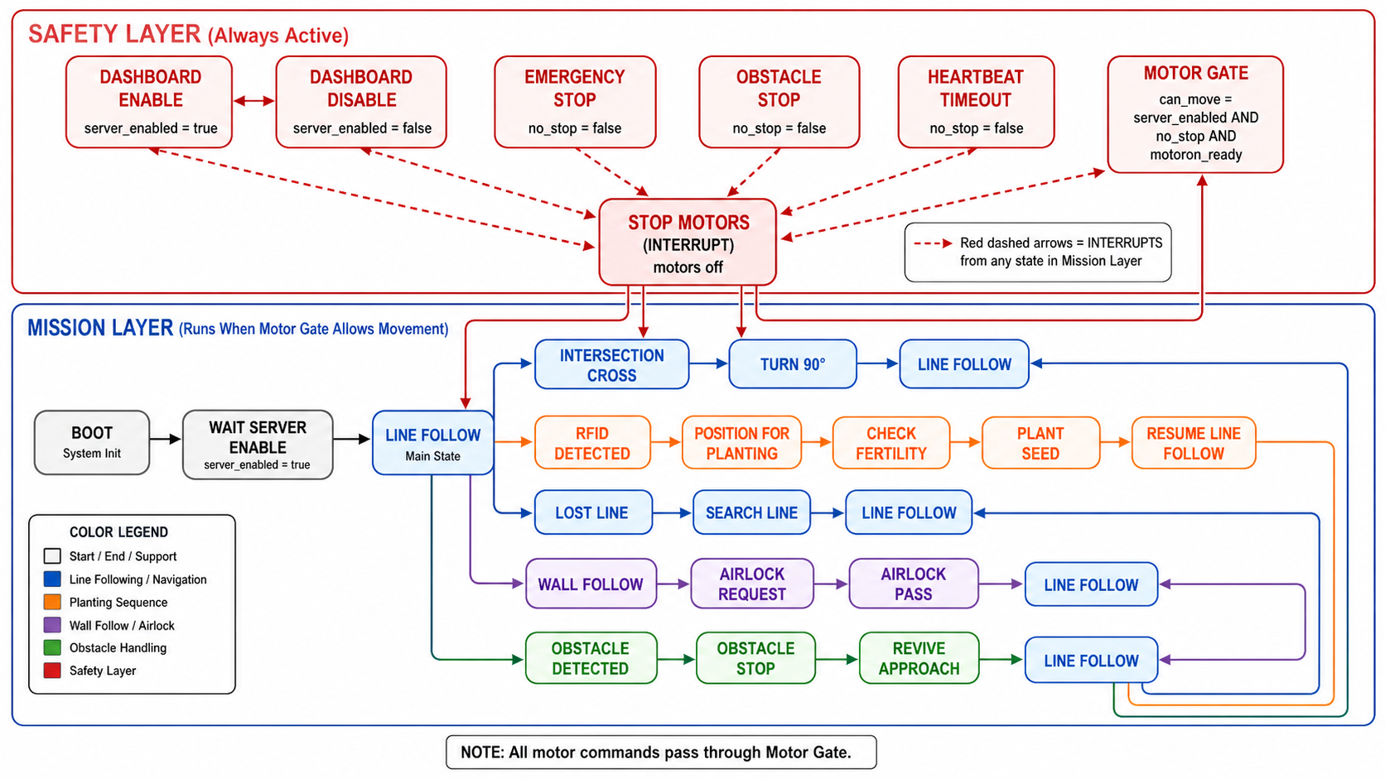
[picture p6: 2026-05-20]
docs/planning/state_machine.png

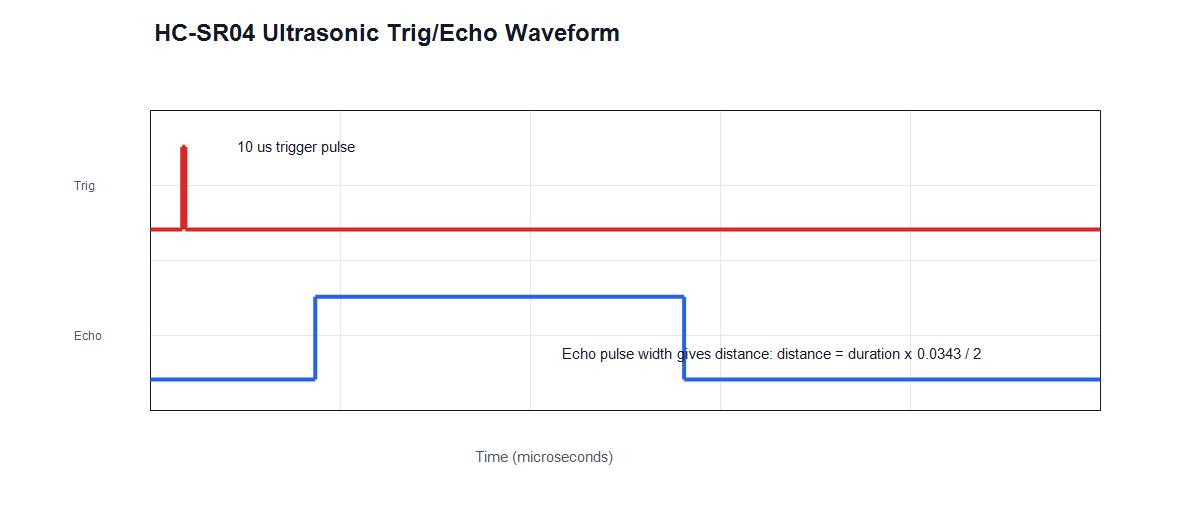
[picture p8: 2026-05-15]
waveform_figures/03_ultrasonic_trig_echo_waveform.png

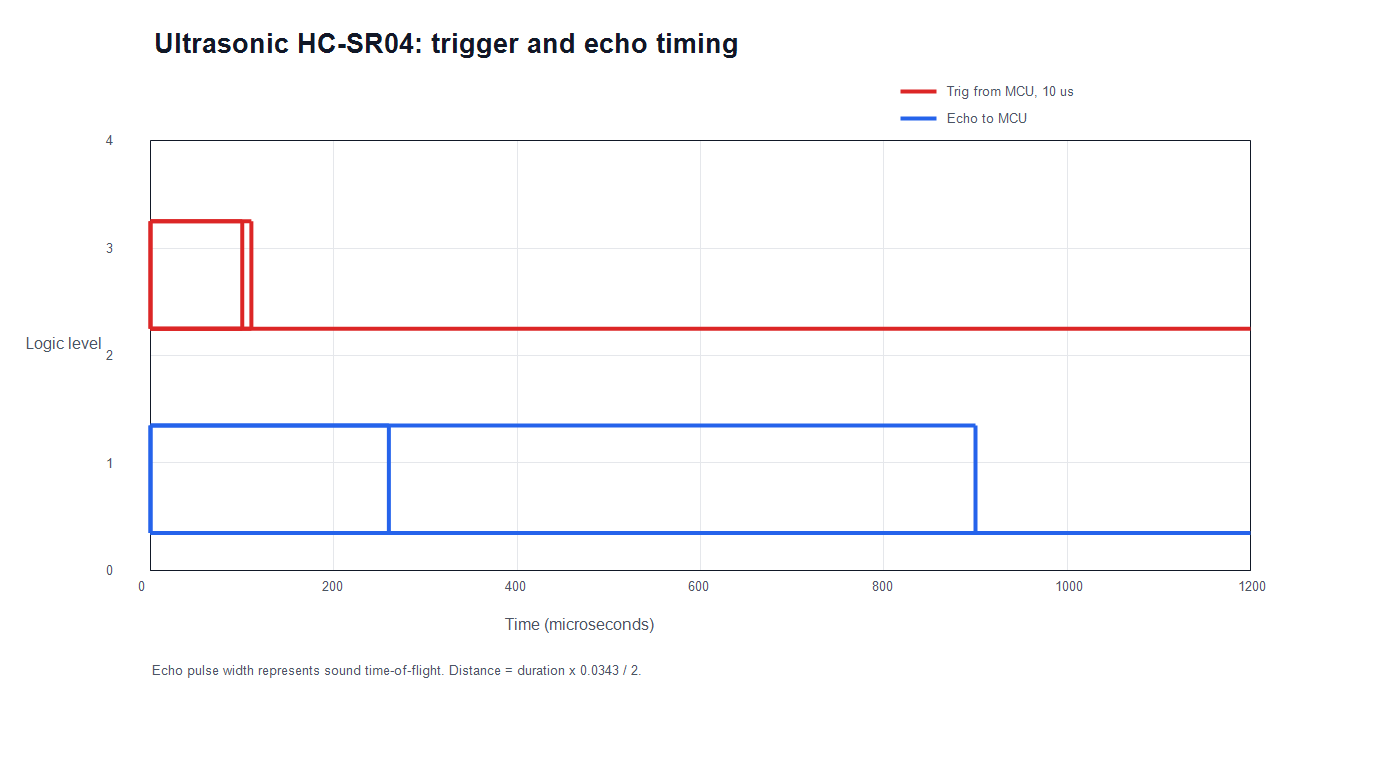
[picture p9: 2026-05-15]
waveform_figures_fixed/03_ultrasonic_trig_echo.png

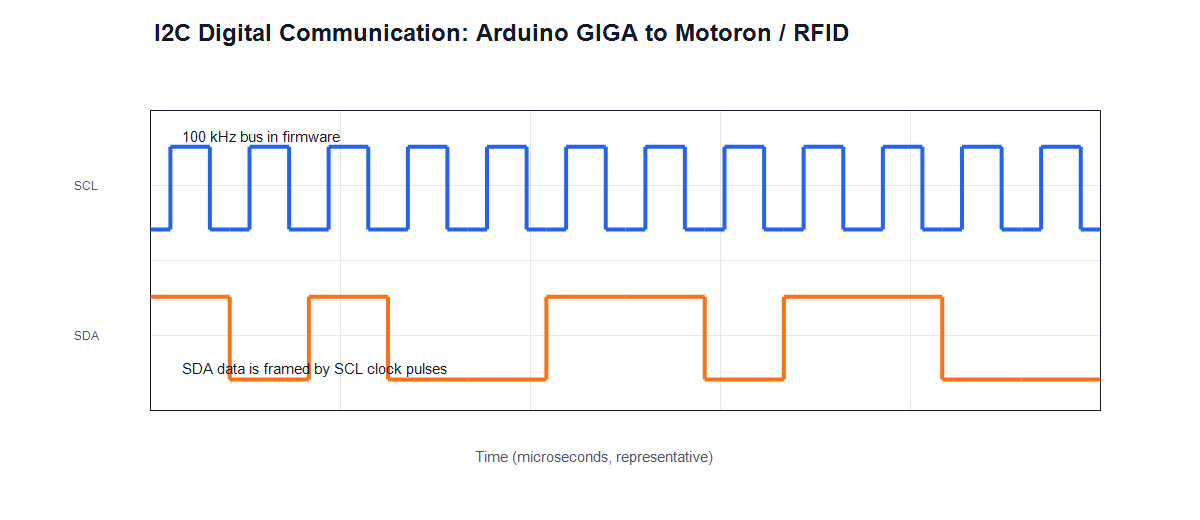
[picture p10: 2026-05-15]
waveform_figures/01_i2c_motoron_rfid_waveform.png

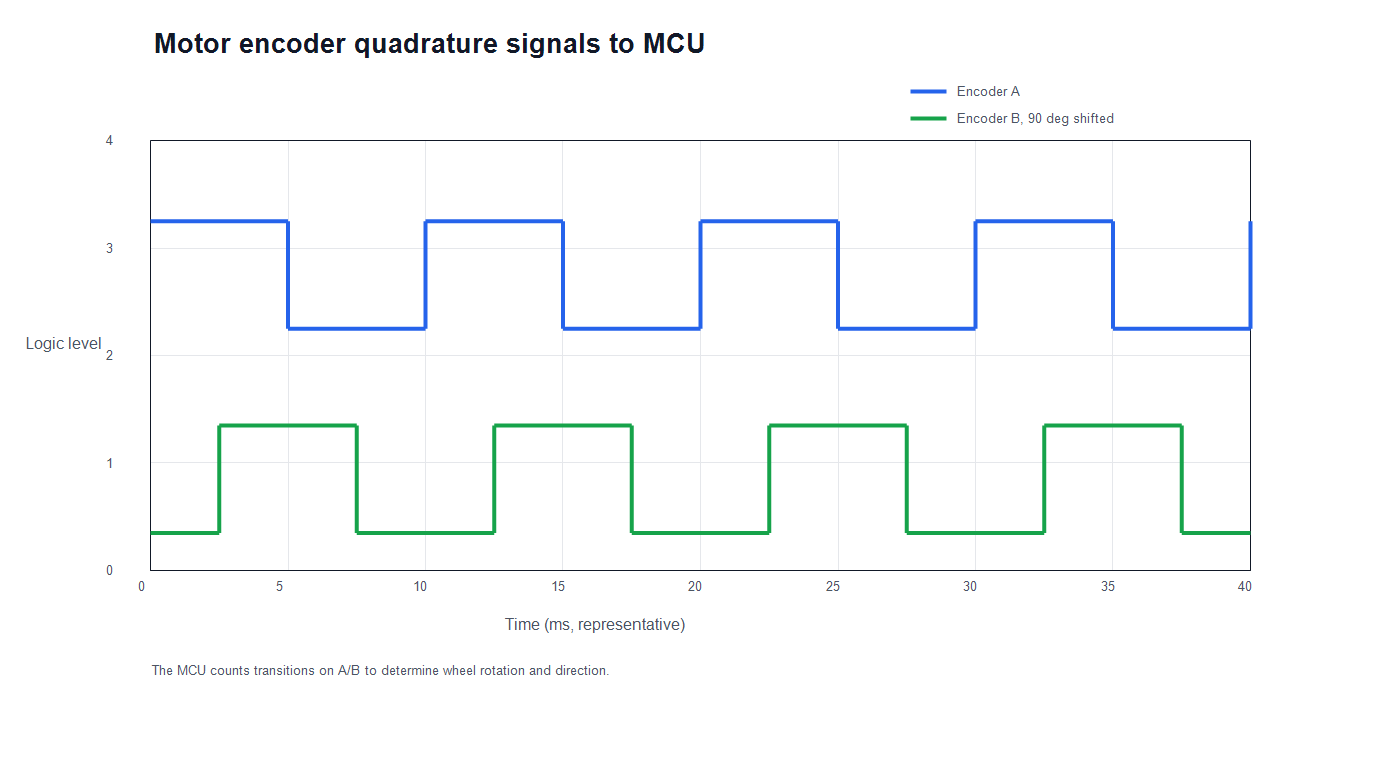
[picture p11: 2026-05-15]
waveform_figures_fixed/05_encoder_quadrature.png

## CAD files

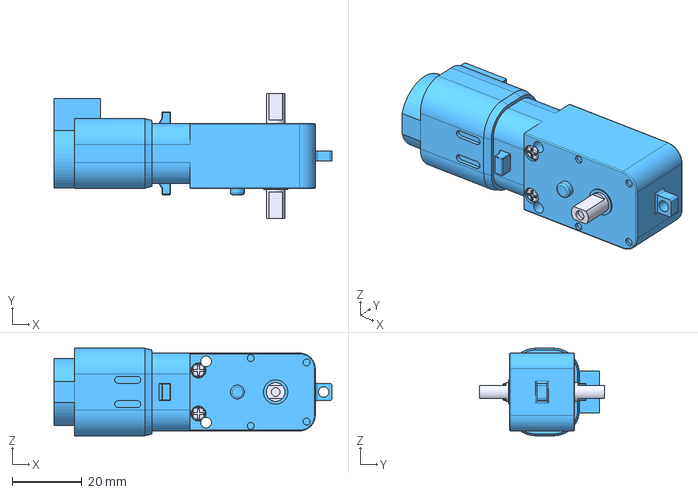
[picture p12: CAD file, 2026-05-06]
cad/ROB-16413 - blue motor v1.step
80.0 x 36.0 x 25.2 mm

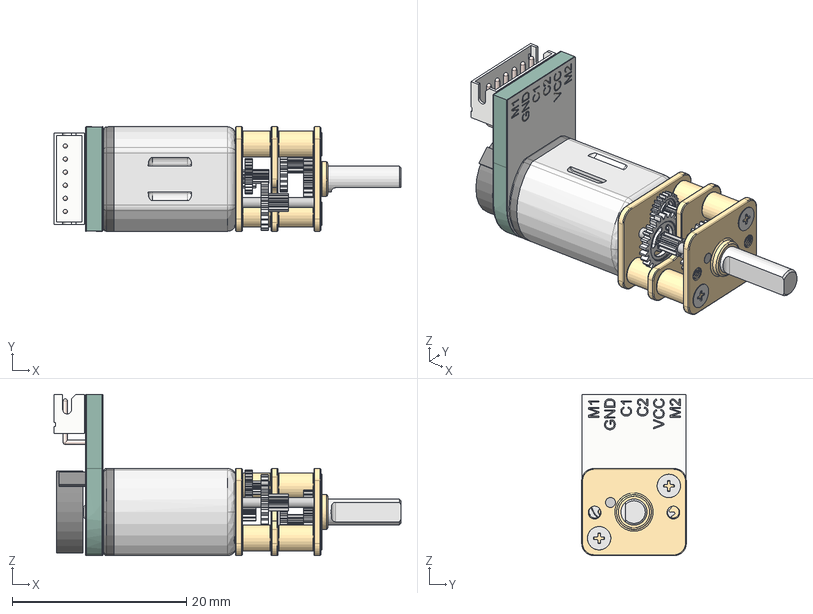
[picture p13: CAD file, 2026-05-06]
cad/N20 Mini Micro Metall Gear Motor DC 3-6-12V v1.step
39.8 x 12.0 x 18.5 mm

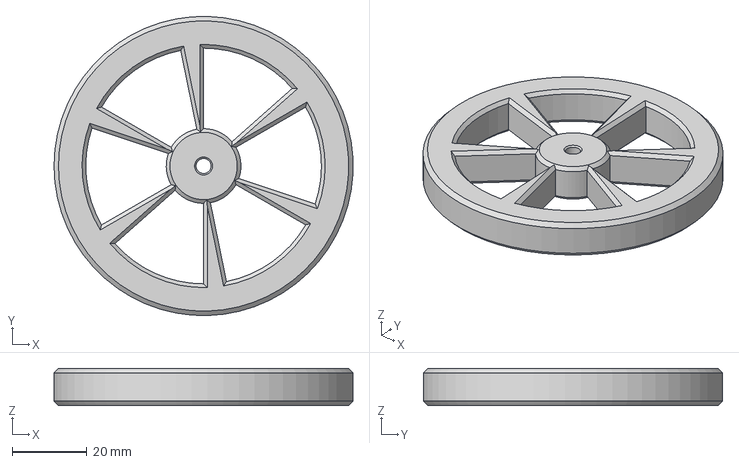
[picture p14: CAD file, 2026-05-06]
cad/80x10 wheel v4.step
79.9 x 80.0 x 10.0 mm

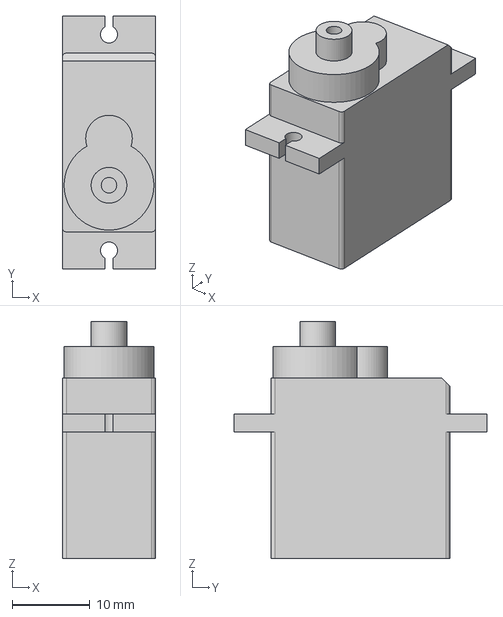
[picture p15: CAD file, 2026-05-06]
cad/DS-S006L servo v1.step
12.0 x 32.5 x 30.5 mm

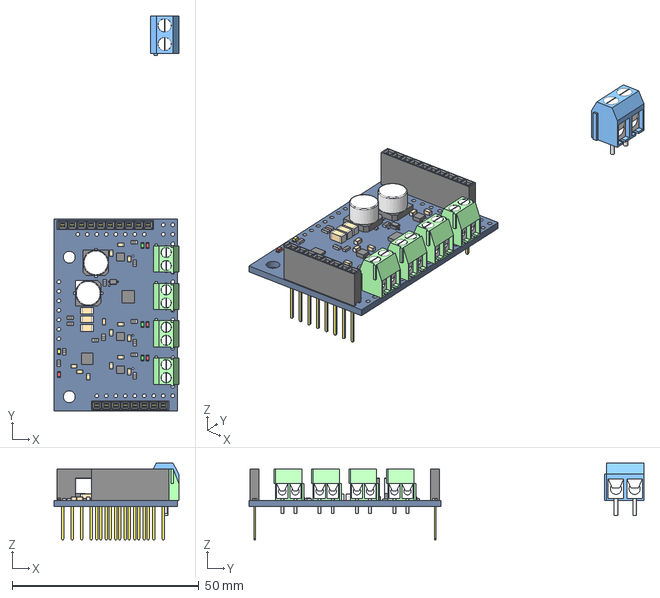
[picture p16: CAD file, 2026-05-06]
cad/motoron-m3s550 v1.step
33.4 x 105.7 x 20.5 mm

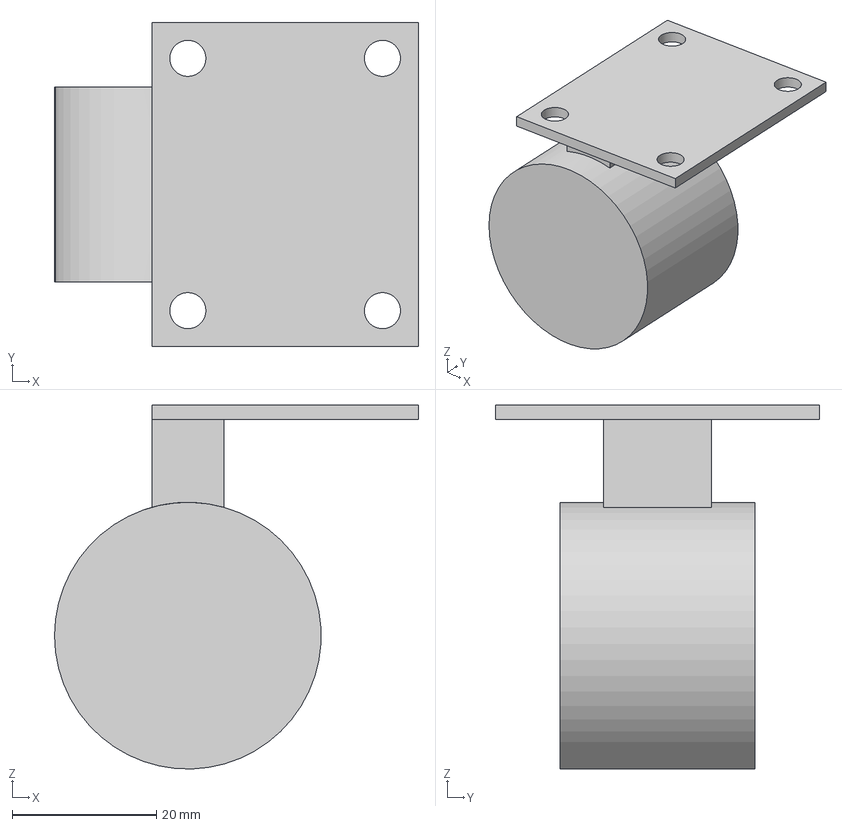
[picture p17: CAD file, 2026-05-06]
cad/trolley_wheel v2.step
50.5 x 45.0 x 50.5 mm

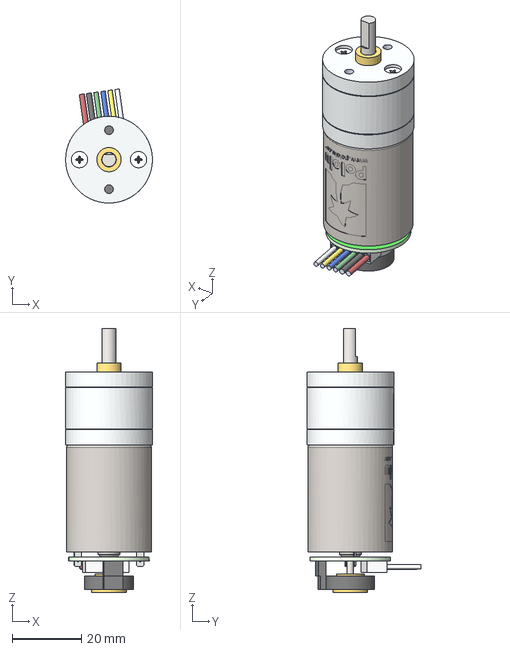
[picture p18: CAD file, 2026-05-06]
cad/25D-metal-gearmotor-encoder v1.step
25.0 x 32.9 x 76.0 mm

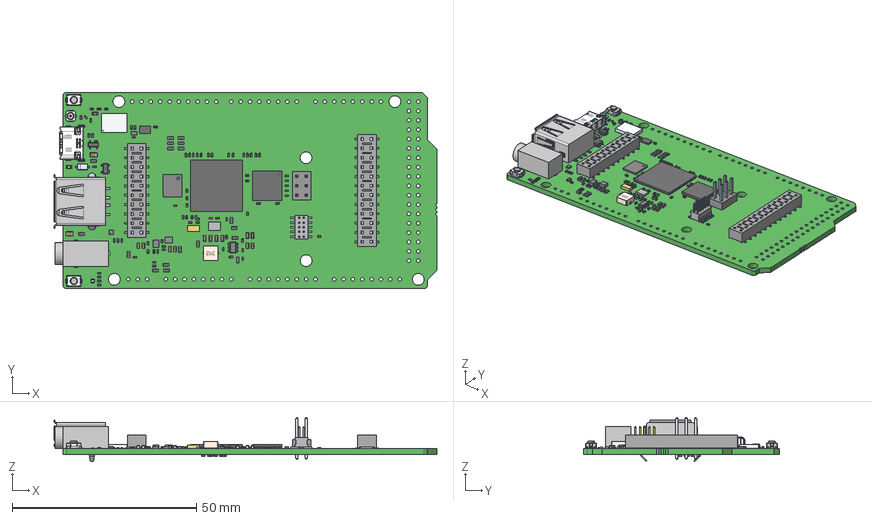
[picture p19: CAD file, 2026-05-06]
cad/arduino_giga v1.step
104.0 x 53.3 x 12.1 mm
RES-0402 x 24
Extruded
ball x 9
Thermal_Shape
Leader x 6
Extruded_1
CAP-0402 x 65
CX90B-16P_3D
CAP-0603 x 13
RES-0603 x 16
FER-0603
SRP-4020 Inductor
c-292303-7-e-3d
Extruded_2
PTS820J20KSMTRLFS x 2
_FTSH-105-01-F-DV_body
_FTSH-105-01-F-DV_pins1
_FTSH-105-01-F-DV_pins2
PRTR5V0U2X x 2
SOD123
_HLE-112-02-DV_socket
_C-132-12-12-DV
CAP-0805 x 2
_HLE-110-02-DV_socket
_C-132-12-10-DV
2x3 Header
Extruded_3
STM32H747XI
AS4C4M16SA-C&I
ATECC608A-MAH
SiT1532
SMLP34RGB
HSMx-190
Murata Logo 3
LBEE5KL1DX
U_FL-R-SMT(10)

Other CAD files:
cad/pololu-25d-mm-metal-gearmotor-bracket.dxf
cad/main_build.f3z

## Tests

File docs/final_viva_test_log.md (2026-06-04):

# Final Viva/Test Run Log

## Test Information

**Date:** 5 June
**Code version:** `Jason_combined_code/`
**Main file:** `Jason_combined_code/Main.ino`
**Purpose:** Final integrated robot test for the viva/test run.

---

## 1. Startup and Calibration Test

### What was tested

The robot startup sequence, including IR line sensor calibration and IMU gyro calibration.

### How it was tested

The robot was powered on and the final code was uploaded from `Jason_combined_code/`. During startup, the line sensor array was moved over the floor and black line for calibration. The robot was then placed flat and still while the IMU gyro bias calibration was completed.

### What worked

* The robot entered the calibration sequence correctly.
* The IR sensors produced calibrated values.
* The IMU gyro calibration completed after the robot was kept still.
* Serial Monitor printed calibration and ready messages.

### What did not work / limitations

* The calibration quality depended on moving the sensors across both the floor and the line properly.
* If the robot was moved during IMU calibration, the turn accuracy became worse.

### Evidence

* Serial Monitor output showing calibration messages.
* Photo/screenshot of Serial Monitor.
* Short video of startup calibration if available.

---

## 2. Line Following Test

### What was tested

The 9-channel line sensor reading, line detection, line position estimation, and proportional motor correction.

### How it was tested

The robot was placed on the black line after calibration. The robot followed the track using the line-following control loop.

### What worked

* The robot detected the black line.
* The robot adjusted left and right motor speeds based on line position.
* The robot could continue moving along straight sections of the line.

### What did not work / limitations

* Line following became less stable when the lighting changed or when the sensor height changed.
* Sharp junctions required careful calibration and sometimes caused unstable behaviour.

### Evidence

* Video of the robot following the line.
* Serial Monitor output showing line position, error, and motor commands.

---

## 3. IMU Turning Test

### What was tested

IMU-based 90-degree and 180-degree turning using gyro Z-axis integration.

### How it was tested

The robot was commanded to turn left/right using the turning functions. The robot used gyro angle integration and attempted to reacquire the line after turning.

### What worked

* The robot could rotate using IMU angle feedback.
* The turn functions stopped the motors after the target angle or line detection.
* The robot could reacquire the line after some turns.

### What did not work / limitations

* Turning accuracy depended on successful gyro calibration.
* IMU drift and vibration affected the final angle.
* Some turns required retuning of target angles because the physical robot overshot slightly.

### Evidence

* Serial Monitor output showing turn angle.
* Video of 90-degree and/or 180-degree turns.

---

## 4. RFID and Server Test

### What was tested

RFID tag detection and server communication using the serial command `9`.

### How it was tested

An RFID tag was placed near the reader. The serial command `9` was sent through Serial Monitor. The robot scanned the RFID tag, sent an `isFertile` request to the server, and printed the reply.

### What worked

* The RFID reader detected tag UIDs.
* The robot sent the tag information to the server.
* The robot printed the UID, fertility state, and x/y position when a reply was received.

### What did not work / limitations

* RFID detection depended on tag distance and orientation.
* Server replies sometimes depended on WiFi/MQTT connection quality.
* If the tag was moved too quickly, the RFID reader sometimes missed it.

### Evidence

* Screenshot of Serial Monitor showing RFID UID and server reply.
* Photo/video of RFID test.

---

## 5. Obstacle Avoidance Test

### What was tested

The scripted obstacle avoidance sequence using the forward ultrasonic sensor, RFID junction detection, line following, and IMU turning.

### How it was tested

The serial command `8` was used to reset and select the obstacle avoidance sequence. An obstacle was placed in front of the robot on the test path.

### What worked

* The forward ultrasonic sensor detected an obstacle.
* The robot entered the obstacle avoidance state machine.
* The robot performed a scripted sequence of turns and straight movements.

### What did not work / limitations

* The sequence depended on the obstacle and junction layout matching the tested route.
* Ultrasonic readings could fluctuate if the obstacle surface was angled.
* If RFID junction detection failed, the sequence could stop or become inaccurate.

### Evidence

* Video of the obstacle avoidance attempt.
* Serial Monitor output showing obstacle avoidance state changes.

---

## 6. Tunnel / Wall Following Test

### What was tested

Tunnel entry, side ultrasonic wall following, gate detection, and exit gate handling.

### How it was tested

The robot was placed near the tunnel entrance. The forward ultrasonic sensor was used to detect gates, and the side ultrasonic sensor was used for wall-following correction.

### What worked

* The robot could detect the base gate using the forward ultrasonic sensor.
* The robot could use side distance for wall following.
* The motor speeds changed based on side distance error.

### What did not work / limitations

* Wall following depended on the side wall being on the expected side.
* Ultrasonic readings could be noisy near corners or angled surfaces.
* Thresholds required tuning for the real arena setup.

### Evidence

* Video of tunnel/wall-following test.
* Serial Monitor output showing gate/wall-following messages.

---

## 7. Seed Dispenser Test

### What was tested

The upper and lower servo sequence for dispensing one seed.

### How it was tested

The seed dispenser was triggered using the planting function. The upper servo opened and closed first, then the lower servo opened and closed.

### What worked

* The upper and lower servo gates moved in the expected sequence.
* The dispenser could release a seed when the mechanism was aligned correctly.

### What did not work / limitations

* The result depended on seed size and mechanical friction.
* Servo angles needed manual adjustment to avoid jamming.
* The manually generated servo pulses must continue to be serviced during longer code sections.

### Evidence

* Short video of the servo/seed dispenser test.
* Photo of the dispenser mechanism.

---

## Final Notes

The `Jason_combined_code/` folder was used as the final integrated code version. The main tested behaviours included startup calibration, line following, IMU turning, RFID/server testing, obstacle avoidance, tunnel/wall following, and seed dispensing.

Some behaviours worked reliably in controlled tests, while others depended on environmental conditions such as lighting, sensor alignment, WiFi/server connection, RFID tag position, and ultrasonic sensor noise.

The final code is suitable as the viva/test run version, but some behaviours may still require manual setup, calibration, or reset during physical testing.

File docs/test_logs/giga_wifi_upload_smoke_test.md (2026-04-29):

# Arduino GIGA R1 WiFi/upload smoke test

Source experiment: local `giga_test` PlatformIO project.

## What was validated

- Arduino GIGA R1 builds with PlatformIO using `ststm32`, `giga_r1_m7`, and Arduino framework.
- Windows DFU upload works after binding the DFU interface `2341:0366` interface 0 to WinUSB with Zadig.
- On this machine, PlatformIO's automatic 1200 bps serial reset can fail with `Cannot configure port`, so the project uses a pre-upload script to skip serial touch/flushing.
- Manual upload flow works: double-click reset to enter DFU, then run PlatformIO Upload.
- Serial Monitor on the normal COM port works at `115200`.
- Basic `WiFi.begin(ssid, password)` test reaches the connection loop and prints status over serial.

## Safe WiFi test sketch

Do not commit real WiFi credentials. Put temporary credentials in a local-only config file or edit them only while testing.

```cpp
#include <Arduino.h>
#include <WiFi.h>

const char* ssid = "YOUR_WIFI_SSID";
const char* password = "YOUR_WIFI_PASSWORD";

void setup() {
    Serial.begin(115200);
    while (!Serial && millis() < 1500) {
        delay(10);
    }

    Serial.println("Connecting to WiFi...");
    WiFi.begin(ssid, password);

    while (WiFi.status() != WL_CONNECTED) {
        delay(1000);
        Serial.print(".");
    }

    Serial.println();
    Serial.println("WiFi connected!");
    Serial.print("IP address: ");
    Serial.println(WiFi.localIP());
}

void loop() {}
```

## Notes

- Use a 2.4 GHz WiFi network or hotspot compatibility mode first.
- Prefer an ASCII SSID while debugging. Non-ASCII SSIDs can make serial/source encoding harder to reason about.
- If upload says `No DFU capable USB device available`, the board is probably not in DFU mode.
- If upload says `Cannot claim interface`, check Zadig and set `2341:0366` interface 0 to WinUSB.

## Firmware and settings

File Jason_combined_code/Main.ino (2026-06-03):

//i think this one works

#include <Arduino.h>
#include <Wire.h>
#include <Motoron.h>
#include <math.h>
#include <MFRC522_I2C.h> //To be tested
#include "ArenaTypes.h"  // ArenaPoint / ArenaHeading / RFIDLocation / Test8ReviveTarget

// =====================================================
// Integrated robot_config.hpp
// =====================================================
bool turnAngleOnly(float max_degrees, int8_t direction);
bool suppress_junction_turns = false;

namespace robot_config {

constexpr const char* WIFI_SSID = "PhaseSpaceNetwork_2.4G";
constexpr const char* WIFI_PASSWORD = "8igMacNet";
constexpr uint16_t UDP_PORT = 4210;

constexpr bool ENABLE_TOP_RGB = true;
constexpr bool ENABLE_MECHANICAL_KILL_BUTTON = true;
constexpr bool ENABLE_REVIVE_BUTTON = true;
constexpr bool ENABLE_QTR_STATUS = true;
constexpr bool ENABLE_ULTRASONIC_STATUS = true;
constexpr bool ENABLE_RFID_STATUS = true;
constexpr bool ENABLE_SEED_DISPENSER = true;

constexpr int TOP_RGB_RED_PIN = 39;
constexpr int TOP_RGB_BLUE_PIN = 37;
constexpr int TOP_RGB_GREEN_PIN = 35;
constexpr bool TOP_RGB_COMMON_ANODE = false;

constexpr int MECHANICAL_KILL_BUTTON_PIN = 33;
constexpr int REVIVE_BUTTON_PIN = 13;

constexpr float MOTOR_GEAR_RATIO = 100.0f;
constexpr float MOTOR_RAW_CPR = 24.0f;

constexpr uint16_t QTR_RC_TIMEOUT_US = 1000;
constexpr bool QTR_LINE_IS_HIGH_RAW = true;
constexpr bool QTR_FOLLOW_BLACK_LINE = true;
constexpr uint16_t QTR_LINE_DETECT_ON_THRESHOLD = 650;
constexpr uint16_t QTR_LINE_DETECT_OFF_THRESHOLD = 450;

constexpr int SEED_UPPER_SERVO_PIN = 36;
constexpr int SEED_LOWER_SERVO_PIN = 38;
constexpr int SEED_UPPER_CLOSED_ANGLE = 90;
constexpr int SEED_UPPER_OPEN_ANGLE = 0;
constexpr int SEED_LOWER_CLOSED_ANGLE = 0;
constexpr int SEED_LOWER_OPEN_ANGLE = 90;
constexpr int SEED_SERVO_MIN_PULSE_US = 500;
constexpr int SEED_SERVO_MAX_PULSE_US = 2500;
constexpr unsigned long SEED_SERVO_PERIOD_US = 20000;
constexpr unsigned long SEED_UPPER_OPEN_MS = 700;
constexpr unsigned long SEED_UPPER_CLOSE_MS = 1000;
constexpr unsigned long SEED_LOWER_OPEN_MS = 700;
constexpr unsigned long SEED_LOWER_CLOSE_MS = 500;

constexpr uint8_t RFID_I2C_ADDRESS = 0x28;
constexpr int RFID_RESET_PIN = -1;

}

// =====================================================
// Mission / tunnel state
// =====================================================

enum class MissionPhase {
  BaseToGate,
  Tunnel,
  Arena,
  ArenaToEntryGate,      // line-follow inside arena toward Tunnel A surface door
  TunnelReturn,          // inbound airlock: through Tunnel A back into the base
  BaseReturnToParking    // line-follow inside base to the robot collection area
};

enum class TunnelState {
  WaitAtBaseGate,
  DrivingIntoTunnel,
  WallFollow,
  WaitAtExitGate,
  PassingExitGate
};

// Inbound airlock sub-states (Tunnel A). Mirror of TunnelState
// but the doors open in response to a WiFi request to the
// server instead of being detected passively.
enum class TunnelReturnState {
  ApproachGate,          // close in on the surface-side door (forward US triggers)
  RequestOuterDoor,      // send WiFi "open Tunnel A" request (stubbed)
  WaitOuterDoor,         // poll forward US until the door has opened
  DrivingIntoAirlock,    // crawl forward into the airlock past the door frame
  WallFollow,            // follow ramp wall down to the base-side door
  RequestInnerDoor,      // send WiFi "open inner door" request (stubbed)
  WaitInnerDoor,         // poll forward US until the inner door has opened
  PassingInnerDoor,      // drive through into the base
  Done                   // hand off to BaseReturnToParking
};

// =====================================================
// Obstacle-avoidance swerve state
// =====================================================

enum class SwerveState {
  LineFollow,
  ApproachObstacle,
  TurnRight,
  GoStraightUntilJunc1,
  TurnLeft1,
  GoStraightUntilJunc2,
  TurnLeft2,
  GoStraightUntilJunc3,
  Done
};

MissionPhase mission_phase = MissionPhase::BaseToGate;
TunnelState tunnel_state = TunnelState::WaitAtBaseGate;
TunnelReturnState tunnel_return_state = TunnelReturnState::ApproachGate;

// Arena pathfinder goal. Higher-level mission code (find next fertile
// cell, head for parking, etc.) sets these; the Arena phase consumes
// them in option (b). When arena_have_goal == false, the swerve runs.
ArenaPoint arena_goal = {-1, -1};
bool arena_have_goal = false;


// =====================================================
// State
// =====================================================

enum class FollowState {
  Idle,
  FollowLine,
  CrossIntersection,
  LineGap,
  LostLine,
};

enum class JunctionType {
  None,
  Straight,
  LeftTurn,
  RightTurn,
  TIntersection,
  WideIntersection,
  Lost
};

enum class StartupCalState {
  CalibratingIR,
  WaitingForStillIMU,
  CalibratingIMU,
  Ready
};

StartupCalState startup_cal_state = StartupCalState::CalibratingIR;

FollowState follow_state = FollowState::Idle;

JunctionType last_junction_type = JunctionType::None;
unsigned long last_junction_detect_ms = 0;

// =====================================================
// Timing constants
// =====================================================

constexpr unsigned long SERIAL_WAIT_TIMEOUT_MS = 5000;
constexpr unsigned long CALIBRATION_TIME_MS = 5000;
constexpr unsigned long CONTROL_INTERVAL_MS = 30;
constexpr unsigned long LINE_STATUS_INTERVAL_MS = 250;
constexpr unsigned long INTERSECTION_CROSS_MS = 500;
constexpr unsigned long RFID_SCAN_COOLDOWN_MS = 1500;
constexpr unsigned long LINE_GAP_FORWARD_MS = 500;
constexpr int16_t LINE_GAP_SPEED = 220;

constexpr unsigned long IMU_STILL_WAIT_MS = 3000;
unsigned long imu_still_start_ms = 0;

// =====================================================
// IMU constants and globals
// =====================================================

constexpr unsigned long TURN_TIMEOUT_MS = 5000;
constexpr uint16_t GYRO_BIAS_SAMPLE_COUNT = 200;
constexpr unsigned long GYRO_BIAS_SAMPLE_DELAY_MS = 5;

constexpr float ITG320X_LSB_PER_DPS = 14.375f;
constexpr float GYRO_Z_DEADBAND_DPS = 0.4f;

constexpr float TURN_90_TARGET_DEG = 100.0f;
constexpr float TURN_180_TARGET_DEG = 190.0f;

constexpr float TURN_90_IGNORE_LINE_UNTIL_DEG = 60.0f;
constexpr float TURN_180_IGNORE_LINE_UNTIL_DEG = 120.0f;

constexpr uint16_t TURN_LINE_DETECT_THRESHOLD = 600;
constexpr uint16_t TURN_CENTER_DETECT_THRESHOLD = 550;

constexpr uint8_t ADXL345_ADDRESS = 0x53;
constexpr uint8_t ADXL345_DEVID = 0x00;
constexpr uint8_t ADXL345_POWER_CTL = 0x2D;
constexpr uint8_t ADXL345_DATA_FORMAT = 0x31;

constexpr uint8_t ITG320X_ADDRESS = 0x68;
constexpr uint8_t ITG320X_WHO_AM_I = 0x00;
constexpr uint8_t ITG320X_SMPLRT_DIV = 0x15;
constexpr uint8_t ITG320X_DLPF_FS = 0x16;
constexpr uint8_t ITG320X_TEMP_OUT_H = 0x1B;
constexpr uint8_t ITG320X_PWR_MGM = 0x3E;

constexpr uint8_t HMC5883L_ADDRESS = 0x1E;
constexpr uint8_t HMC5883L_CONFIG_A = 0x00;
constexpr uint8_t HMC5883L_CONFIG_B = 0x01;
constexpr uint8_t HMC5883L_MODE = 0x02;
constexpr uint8_t HMC5883L_ID_A = 0x0A;

constexpr uint8_t QMC5883L_ADDRESS = 0x0D;
constexpr uint8_t QMC5883L_CONTROL_1 = 0x09;
constexpr uint8_t QMC5883L_SET_RESET = 0x0B;

constexpr uint8_t BMP280_ADDRESS_1 = 0x76;
constexpr uint8_t BMP280_ADDRESS_2 = 0x77;
constexpr uint8_t BMP280_CHIP_ID = 0xD0;
constexpr uint8_t BMP280_RESET = 0xE0;
constexpr uint8_t BMP280_CTRL_MEAS = 0xF4;
constexpr uint8_t BMP280_CONFIG = 0xF5;

TwoWire* imu_bus = &Wire;
const char* imu_bus_name = "Wire D20/D21";

bool adxl345_ready = false;
bool itg320x_ready = false;
bool hmc5883l_ready = false;
bool bmp280_ready = false;
bool compass_is_qmc5883 = false;

uint8_t bmp280_address = BMP280_ADDRESS_1;

float gyro_z_bias_dps = 0.0f;
float turn_angle_deg = 0.0f;

unsigned long last_gyro_update_us = 0;

struct Axis3 {
  int16_t x;
  int16_t y;
  int16_t z;
};

// =====================================================
// Line sensor globals
// =====================================================

constexpr uint8_t SENSOR_COUNT = 9;
constexpr uint16_t LINE_POSITION_SCALE = 1000;
constexpr int32_t LINE_CENTER = ((SENSOR_COUNT - 1) * LINE_POSITION_SCALE) / 2;

constexpr uint16_t INTERSECTION_THRESHOLD = 800;
constexpr uint8_t INTERSECTION_SENSOR_COUNT = 7;

constexpr unsigned long LOST_REVERSE_MS = 250;
constexpr unsigned long LOST_GENTLE_SEARCH_MS = 900;
constexpr unsigned long TURN_RECOVERY_MEMORY_MS = 4000;

constexpr int16_t LOST_REVERSE_SPEED = 210;
constexpr int16_t LOST_GENTLE_TURN_SPEED = 180;
constexpr int16_t LOST_HARD_TURN_SPEED = 260;

const uint8_t sensor_pins[SENSOR_COUNT] = {2, 3, 4, 5, 8, 9, 10, 11, 12};

uint16_t raw_values[SENSOR_COUNT] = {};
uint16_t min_values[SENSOR_COUNT] = {};
uint16_t max_values[SENSOR_COUNT] = {};
uint16_t calibrated_values[SENSOR_COUNT] = {};

unsigned long calibration_start_ms = 0;
unsigned long state_start_ms = 0;
unsigned long last_control_ms = 0;
unsigned long last_line_status_ms = 0;

int32_t last_error = 0;
int8_t last_line_side = 0;
int8_t last_turn_recovery_side = 0;
unsigned long last_turn_end_ms = 0;

bool calibration_done = false;
bool line_detected = false;
bool run_enabled = true;

// =====================================================
// Motor globals
// =====================================================

MotoronI2C mc(0x10);

const uint8_t MOTOR_LEFT  = 1;
const uint8_t MOTOR_RIGHT = 2;
const uint8_t MOTOR_AUX   = 3;

const double MOTOR_RATIO = 1.44 / 1.4681;

constexpr int16_t BASE_SPEED = 250;
constexpr int16_t TURN_SPEED = 230;

const int16_t MAX_SPEED_R = 800;
const int16_t MAX_SPEED_L = 800;

constexpr float LINE_KP = 0.055f;

constexpr int8_t LEFT_FORWARD_SIGN = 1;
constexpr int8_t RIGHT_FORWARD_SIGN = 1;

const uint16_t ACCEL = 800;
const uint16_t DECEL = 800;

bool motoron_ready = false;

int16_t last_left_command = 0; 
int16_t last_right_command = 0;

unsigned long lastPrintTime = 0;
unsigned long lastScanTime = 0;

// =====================================================
// Encoder globals
// =====================================================

const uint8_t ENC_LEFT_A  = 28;
const uint8_t ENC_LEFT_B  = 26;
const uint8_t ENC_RIGHT_A = 22;
const uint8_t ENC_RIGHT_B = 24;

const double wheel_diameter = 38.35;

volatile long encoderLeftCount = 0;
volatile long encoderRightCount = 0;

// =====================================================
// LED and button globals
// =====================================================

const int redPin = robot_config::TOP_RGB_RED_PIN;
const int greenPin = robot_config::TOP_RGB_GREEN_PIN;
const int bluePin = robot_config::TOP_RGB_BLUE_PIN;

const int OffButtonPin = robot_config::MECHANICAL_KILL_BUTTON_PIN;
const int RevButtonPin = robot_config::REVIVE_BUTTON_PIN;

int previousStateRed = 0;
bool running = true;
bool Reviving = false;
int previousOffButtonPressed = 1;

// =====================================================
// RFID globals
// =====================================================

constexpr uint8_t RFID_ADDR = robot_config::RFID_I2C_ADDRESS;
MFRC522_I2C rfid(RFID_ADDR, robot_config::RFID_RESET_PIN, &Wire1);

// =====================================================
// Servo globals
// =====================================================

constexpr int SERVO1_PIN = robot_config::SEED_UPPER_SERVO_PIN;
constexpr int SERVO2_PIN = robot_config::SEED_LOWER_SERVO_PIN;

constexpr int UPPER_CLOSED = robot_config::SEED_UPPER_CLOSED_ANGLE;
constexpr int UPPER_OPEN = robot_config::SEED_UPPER_OPEN_ANGLE;
constexpr int LOWER_CLOSED = robot_config::SEED_LOWER_CLOSED_ANGLE;
constexpr int LOWER_OPEN = robot_config::SEED_LOWER_OPEN_ANGLE;

constexpr int SERVO_MIN_PULSE_US = robot_config::SEED_SERVO_MIN_PULSE_US;
constexpr int SERVO_MAX_PULSE_US = robot_config::SEED_SERVO_MAX_PULSE_US;
constexpr unsigned long SERVO_PERIOD_US = robot_config::SEED_SERVO_PERIOD_US;

int upper_pulse_us = 1500;
int lower_pulse_us = 1500;
int seeds = 5;

unsigned long last_servo_frame_us = 0;


// =====================================================
// Tunnel entry / wall-following logic
// Merged from Tunnel_Entry.ino
// =====================================================

constexpr float GATE_STOP_MM           = 100.0f;  // base exit gate detected ahead
constexpr float BASE_DOOR_OPEN_MM      = 250.0f;  // base gate has opened
constexpr float TARGET_SIDE_MM         = 60.0f;   // wall-follow target distance
constexpr float SIDE_WALL_DETECTED_MM  = 120.0f;  // side wall is found
constexpr float TUNNEL_DOOR_CLOSED_MM  = 50.0f;   // outer door detected ahead
constexpr float TUNNEL_DOOR_OPEN_MM    = 250.0f;  // outer door has opened
constexpr float TUNNEL_DONE_MM         = 500.0f;  // fully through outer door
constexpr float US_MAX_VALID_MM        = 2000.0f;
constexpr float US_MIN_VALID_MM        = 20.0f;

constexpr uint8_t TUNNEL_TRIG_SIDE     = 47;
constexpr uint8_t TUNNEL_ECHO_SIDE     = 46;
constexpr uint8_t TUNNEL_TRIG_FORWARD  = 52;
constexpr uint8_t TUNNEL_ECHO_FORWARD  = 53;

constexpr float    WALL_KP             = 4.0f;
constexpr int16_t  BASE_RAMP_SPEED     = 400;
constexpr int16_t  WALL_MAX_SPEED      = 600;

constexpr long BASE_EXIT_MIN_DISTANCE_COUNTS = 2000;
constexpr unsigned long BASE_EXIT_DRIVE_TIMEOUT_MS = 3000;

unsigned long tunnel_state_start_ms = 0;
long base_exit_start_counts = 0;

float last_valid_side_mm = TARGET_SIDE_MM;
float last_valid_forward_mm = 1000.0f;

float read_ultrasonic_mm(uint8_t trig_pin, uint8_t echo_pin)
{
  digitalWrite(trig_pin, LOW);
  delayMicroseconds(2);
  digitalWrite(trig_pin, HIGH);
  delayMicroseconds(10);
  digitalWrite(trig_pin, LOW);

  const unsigned long duration = pulseIn(echo_pin, HIGH, 30000);

  if (duration == 0) {
    return -1.0f;
  }

  return (duration * 0.343f) / 2.0f;
}

float side_distance_mm()
{
  const float d = read_ultrasonic_mm(TUNNEL_TRIG_SIDE, TUNNEL_ECHO_SIDE);

  if (d > US_MIN_VALID_MM && d < US_MAX_VALID_MM) {
    last_valid_side_mm = d;
    return d;
  }

  return last_valid_side_mm;
}

float forward_distance_mm()
{
  const float d = read_ultrasonic_mm(TUNNEL_TRIG_FORWARD, TUNNEL_ECHO_FORWARD);

  if (d > US_MIN_VALID_MM && d < US_MAX_VALID_MM) {
    last_valid_forward_mm = d;
    return d;
  }

  return last_valid_forward_mm;
}

void wall_follow_step()
{
  const float d_side = side_distance_mm();
  const float error = d_side - TARGET_SIDE_MM;
  float correction = WALL_KP * error;

  correction = constrain(correction, -300.0f, 300.0f);

  int16_t left_speed  = BASE_RAMP_SPEED - static_cast<int16_t>(correction);
  int16_t right_speed = BASE_RAMP_SPEED + static_cast<int16_t>(correction);

  left_speed  = constrain(left_speed,  -WALL_MAX_SPEED, WALL_MAX_SPEED);
  right_speed = constrain(right_speed, -WALL_MAX_SPEED, WALL_MAX_SPEED);

  setMotors(left_speed, right_speed);
}

void drive_into_tunnel()
{
  setMotors(BASE_RAMP_SPEED / 2, BASE_RAMP_SPEED / 2);
}

void setup_tunnel()
{
  pinMode(TUNNEL_TRIG_SIDE,    OUTPUT);
  pinMode(TUNNEL_ECHO_SIDE,    INPUT);
  pinMode(TUNNEL_TRIG_FORWARD, OUTPUT);
  pinMode(TUNNEL_ECHO_FORWARD, INPUT);

  digitalWrite(TUNNEL_TRIG_SIDE,    LOW);
  digitalWrite(TUNNEL_TRIG_FORWARD, LOW);

  tunnel_state = TunnelState::WaitAtBaseGate;
  tunnel_state_start_ms = millis();
}

void set_tunnel_state(TunnelState next)
{
  if (tunnel_state == next) {
    return;
  }

  tunnel_state = next;
  tunnel_state_start_ms = millis();

  if (next == TunnelState::DrivingIntoTunnel) {
    base_exit_start_counts = getLeftEncoder();
  }
}
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
void loop()
{
  serviceServoPulses();
  update_turn_angle();
  messagesLoop();  // service WiFi/MQTT every tick; safe if WiFi is down

  if (Serial.available() > 0) {
    const char command = static_cast<char>(Serial.read());

    if (command == '0') {
      running = !running;

      if (!running) {
        stopMotors();
        Serial.println("running=0");
      } else {
        Serial.println("running=1");
      }

      return;
    }

    if (command == '9') {
      // RFID + server test: scan one tag, send isFertile to the server,
      // print the raw reply, fertility, and x/y coordinates.
      runRFIDServerTest();
      return;
    }

    if (command == '8') {
      setup_obstacle_avoid();
      mission_phase = MissionPhase::Arena;
      set_follow_state(FollowState::FollowLine);
      last_control_ms = millis();
      Serial.println("Obstacle avoidance sequence reset and selected.");
      return;
    }

    if (command == '4') {
      // Trigger return-to-base flow: pathfind to Tunnel A doorway
      // (9,7) then run the inbound airlock state machine.
      setup_tunnel_return();
      mission_phase = MissionPhase::ArenaToEntryGate;
      Serial.println("Return-to-base sequence selected.");
      return;
    }

    if (command == '7') {
      // Run the revival mission (Test 8).
      RunTest8();
      return;
    }
  }

  const int OffButtonPressed = digitalRead(OffButtonPin);
  const int RevButtonPressed = digitalRead(RevButtonPin);

  Reviving = false;

  if (OffButtonPressed == LOW && previousOffButtonPressed != LOW) {
    running = !running;
    delay(50);
  } else if (RevButtonPressed == LOW) {
    Reviving = true;
    delay(50);
  }

  previousOffButtonPressed = OffButtonPressed;

  read_rc_discharge_times();

  const unsigned long now_ms = millis();

  if (startup_cal_state != StartupCalState::Ready) {
    stopMotors();

    if (startup_cal_state == StartupCalState::CalibratingIR) {
      Blue();
      update_calibration();

      if (now_ms - calibration_start_ms >= CALIBRATION_TIME_MS) {
        print_calibration();

        startup_cal_state = StartupCalState::WaitingForStillIMU;
        imu_still_start_ms = millis();

        Serial.println("IR calibration complete.");
        Serial.println("YELLOW LED: place robot flat and keep it still for IMU calibration.");
      }

      return;
    }

    if (startup_cal_state == StartupCalState::WaitingForStillIMU) {
      Yellow();

      if (now_ms - imu_still_start_ms >= IMU_STILL_WAIT_MS) {
        startup_cal_state = StartupCalState::CalibratingIMU;
        Serial.println("Starting IMU gyro calibration. Keep robot still.");
      }

      return;
    }

    if (startup_cal_state == StartupCalState::CalibratingIMU) {
      Yellow();

      calibrate_gyro_z_bias();

      startup_cal_state = StartupCalState::Ready;
      calibration_done = true;

      Serial.println("All calibration complete. Robot ready.");

      return;
    }
  }

  if (!running) {
    run_enabled = false;
    Flash(previousStateRed);
    previousStateRed++;
    stopMotors();
    delay(25);
    return;
  }

  run_enabled = true;

  if (Reviving) {
    Green();
    stopMotors();
    delay(500);
    setMotors(-BASE_SPEED, -BASE_SPEED);
    return;
  }

  Red();

  // Main now carries out the obstacle-avoidance sequence by default.
  // The older BaseToGate/Tunnel phases are left below so they can still be reused
  // by changing mission_phase, but startup begins directly in MissionPhase::Arena.
  switch (mission_phase) {
    case MissionPhase::BaseToGate:
      if (handleRFID()) {
        return;
      }

      if (forward_distance_mm() <= GATE_STOP_MM) {
        stopMotors();
        Serial.println("Base gate reached - waiting for tunnel entry.");
        mission_phase = MissionPhase::Tunnel;
        set_tunnel_state(TunnelState::WaitAtBaseGate);
        return;
      }

      if (now_ms - last_control_ms >= CONTROL_INTERVAL_MS) {
        last_control_ms = now_ms;
        update_line_following();
      }
      break;

    case MissionPhase::Tunnel:
      run_tunnel_step();
      break;

    case MissionPhase::Arena:
      // Option (b): pathfinder primary, swerve as fallback.
      // arena_have_goal is set by higher-level mission code (e.g. "go to
      // the nearest fertile cell") — wiring for that doesn't exist yet,
      // so by default we still run the trial-tested swerve.
      if (arena_have_goal) {
        if (arenaPathfindTo(arena_goal)) {
          arena_have_goal = false;  // reached it; mission code will set the next goal
        } else {
          // Path planning or driving failed (no pose / no path / obstacle
          // blocked). Fall back to swerve for one tick so we keep moving
          // instead of locking up, then mission code can re-plan.
          if (now_ms - last_control_ms >= CONTROL_INTERVAL_MS) {
            last_control_ms = now_ms;
            run_obstacle_avoid_step();
          }
        }
      } else {
        if (now_ms - last_control_ms >= CONTROL_INTERVAL_MS) {
          last_control_ms = now_ms;
          run_obstacle_avoid_step();
        }
      }
      break;

    case MissionPhase::ArenaToEntryGate:
    case MissionPhase::TunnelReturn:
      run_tunnel_return_step();
      break;

    case MissionPhase::BaseReturnToParking:
      // Placeholder until base-side parking line-follow exists.
      if (now_ms - last_control_ms >= CONTROL_INTERVAL_MS) {
        last_control_ms = now_ms;
        update_line_following();
      }
      break;
  }

  if (now_ms - last_line_status_ms >= LINE_STATUS_INTERVAL_MS) {
    last_line_status_ms = now_ms;
    print_line_status();
  }
}

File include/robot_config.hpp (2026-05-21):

#pragma once

#include <Arduino.h>

// Keep real credentials out of source control. Copy this file locally or edit
// these values while testing.
namespace robot_config {

//constexpr const char* WIFI_SSID = "PhaseSpaceNetwork_2.4G";
//constexpr const char* WIFI_PASSWORD = "8igMacNet";
constexpr const char* WIFI_SSID = "PhaseSpaceNetwork_2.4G";
constexpr const char* WIFI_PASSWORD = "8igMacNet";
constexpr uint16_t UDP_PORT = 4210;

// Final robot demo feature switches. If a pin is wrong or not wired yet, turn
// that feature off here without changing the state machine.
constexpr bool ENABLE_TOP_RGB = true;
constexpr bool ENABLE_MECHANICAL_KILL_BUTTON = true;
constexpr bool ENABLE_REVIVE_BUTTON = true;
constexpr bool ENABLE_QTR_STATUS = true;
constexpr bool ENABLE_ULTRASONIC_STATUS = true;
constexpr bool ENABLE_RFID_STATUS = true;
constexpr bool ENABLE_SEED_DISPENSER = true;

// Top tapping RGB LED. Set false when HIGH=on and LOW=off.
constexpr int TOP_RGB_RED_PIN = 39;//new
constexpr int TOP_RGB_BLUE_PIN = 37;//new
constexpr int TOP_RGB_GREEN_PIN = 35;//new
constexpr bool TOP_RGB_COMMON_ANODE = false;

// Mechanical kill switch button. Uses INPUT_PULLUP: pressed = LOW.
constexpr int MECHANICAL_KILL_BUTTON_PIN = 33;//new

// Front revive interface button. Uses INPUT_PULLUP: pressed = LOW.
// Keep this off the current QTR-RC/IR test pins.
constexpr int REVIVE_BUTTON_PIN = 13;//new

// Starter pin map. Adjust to match the motor driver you choose.
constexpr uint8_t LEFT_ENC_A = 22;
constexpr uint8_t LEFT_ENC_B = 23;
constexpr uint8_t RIGHT_ENC_A = 24;
constexpr uint8_t RIGHT_ENC_B = 25;

// Pololu Dual VNH5019 Motor Driver Shield default Arduino pin mapping.
constexpr uint8_t LEFT_IN_A = 2;
constexpr uint8_t LEFT_IN_B = 4;
constexpr uint8_t LEFT_PWM = 9;
constexpr uint8_t LEFT_ENABLE = 6;
constexpr uint8_t RIGHT_IN_A = 7;
constexpr uint8_t RIGHT_IN_B = 8;
constexpr uint8_t RIGHT_PWM = 10;
constexpr uint8_t RIGHT_ENABLE = 12;

constexpr float MOTOR_GEAR_RATIO = 100.0f;
constexpr float MOTOR_RAW_CPR = 24.0f;

// QTR-RC reflectance sensor array. Physical sensors S1-S9 are wired to
// Arduino digital pins D45-D53 and read by measuring RC discharge time.
constexpr uint8_t QTR_FIRST_ANALOG_PIN = 0;
constexpr size_t QTR_SENSOR_COUNT = 9;
constexpr uint16_t QTR_RC_TIMEOUT_US = 1000;

// Set to 255 if the emitter LEDs are wired directly to power.
constexpr uint8_t QTR_EMITTER_PIN = 255;

// Flip this after checking raw values if black tape gives lower readings.
constexpr bool QTR_LINE_IS_HIGH_RAW = true;
constexpr bool QTR_FOLLOW_BLACK_LINE = true;
constexpr uint8_t QTR_RAW_SAMPLE_COUNT = 8;
constexpr uint8_t QTR_SMOOTHING_PERCENT = 35;
constexpr uint16_t QTR_LINE_DETECT_ON_THRESHOLD = 650;
constexpr uint16_t QTR_LINE_DETECT_OFF_THRESHOLD = 450;
constexpr uint16_t QTR_DEMO_LINE_DETECT_ON_THRESHOLD = 300;
constexpr uint16_t QTR_DEMO_LINE_DETECT_OFF_THRESHOLD = 180;
constexpr bool QTR_DEMO_AUTO_POLARITY = true;
constexpr uint16_t QTR_SURFACE_DECISION_MARGIN = 120;

// Two-servo seed dispenser / planter. The upper gate isolates one seed; the
// lower gate releases it into the tube. D45 is used by the QTR-RC array in the
// integrated demo, so the lower servo uses D43 here.
constexpr int SEED_UPPER_SERVO_PIN = 36;
constexpr int SEED_LOWER_SERVO_PIN = 38;
constexpr int SEED_UPPER_CLOSED_ANGLE = 90;
constexpr int SEED_UPPER_OPEN_ANGLE = 0;
constexpr int SEED_LOWER_CLOSED_ANGLE = 0;
constexpr int SEED_LOWER_OPEN_ANGLE = 90;
constexpr int SEED_SERVO_MIN_PULSE_US = 500;
constexpr int SEED_SERVO_MAX_PULSE_US = 2500;
constexpr unsigned long SEED_SERVO_PERIOD_US = 20000;
constexpr unsigned long SEED_UPPER_OPEN_MS = 700;
constexpr unsigned long SEED_UPPER_CLOSE_MS = 1000;
constexpr unsigned long SEED_LOWER_OPEN_MS = 700;
constexpr unsigned long SEED_LOWER_CLOSE_MS = 500;

// HC-SR04 ultrasonic distance sensor test pins.
// Echo is a 5V signal on many HC-SR04 modules; use a resistor divider before
// feeding it into the 3.3V-only Arduino GIGA input pin.
constexpr uint8_t ULTRASONIC_TRIG_PIN = 52;//new
constexpr uint8_t ULTRASONIC_ECHO_PIN = 53;//new
constexpr float ULTRASONIC_MAX_DISTANCE_CM = 400.0f;
constexpr float ULTRASONIC_WALL_THRESHOLD_CM = 20.0f;

// WS1850S / M5Stack RFID2 I2C reader. If nothing is detected, try 0x3C.
constexpr uint8_t RFID_I2C_ADDRESS = 0x28;
constexpr int RFID_RESET_PIN = -1;

}

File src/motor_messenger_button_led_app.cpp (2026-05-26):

#include <Arduino.h>
#include <MiniMessenger.h>
#include <Motoron.h>
#include <WiFi.h>
#include <Wire.h>

#include "robot_config.hpp"

#if __has_include("secrets.h")
#include "secrets.h"
#else
#include "secrets.example.h"
#endif

#ifndef BOARD_ID
#define BOARD_ID "1"
#endif

#ifndef ENABLE_ULTRASONIC_EMERGENCY_STOP
#define ENABLE_ULTRASONIC_EMERGENCY_STOP 0
#endif

namespace {

constexpr uint8_t MOTOR_LEFT = 1;
constexpr uint8_t MOTOR_RIGHT = 2;
constexpr uint8_t MOTOR_AUX = 3;
constexpr int16_t RUN_SPEED = 300;
constexpr uint8_t RIGHT_MOTOR_TRIM_PERCENT = 95;
constexpr uint16_t MOTOR_ACCEL = 800;
constexpr uint16_t MOTOR_DECEL = 800;
constexpr unsigned long BUTTON_DEBOUNCE_MS = 50;
constexpr unsigned long REGISTER_INTERVAL_MS = 10000;
constexpr unsigned long STATUS_INTERVAL_MS = 1000;
constexpr unsigned long LED_BLINK_INTERVAL_MS = 250;
constexpr unsigned long ULTRASONIC_CHECK_INTERVAL_MS = 50;
constexpr float OBSTACLE_STOP_DISTANCE_CM = 5.0f;
constexpr float OBSTACLE_CLEAR_DISTANCE_CM = 10.0f;
constexpr unsigned long ULTRASONIC_ECHO_TIMEOUT_US =
    static_cast<unsigned long>(robot_config::ULTRASONIC_MAX_DISTANCE_CM * 2.0f * 29.1f);

MiniMessenger messenger;
MotoronI2C motoron;

bool motoron_ready = false;
bool stopped_by_button = true;
bool stopped_by_server = false;
bool stopped_by_obstacle = false;
bool top_red_on = false;
int last_kill_button_reading = HIGH;
int stable_kill_button_state = HIGH;
unsigned long last_kill_button_change_ms = 0;
unsigned long last_register_ms = 0;
unsigned long last_status_ms = 0;
unsigned long last_led_blink_ms = 0;
unsigned long last_ultrasonic_check_ms = 0;
float last_front_distance_cm = -1.0f;

constexpr int16_t trim_right_speed(int16_t speed) {
    return static_cast<int16_t>(
        (static_cast<int32_t>(speed) * RIGHT_MOTOR_TRIM_PERCENT) / 100);
}

bool robot_stopped() {
    return stopped_by_button || stopped_by_server || stopped_by_obstacle || !motoron_ready;
}

uint8_t rgb_level(bool on) {
    if (robot_config::TOP_RGB_COMMON_ANODE) {
        return on ? 0 : 255;
    }
    return on ? 255 : 0;
}

void write_top_rgb(bool red, bool green, bool blue) {
    if (!robot_config::ENABLE_TOP_RGB) {
        return;
    }

    if (robot_config::TOP_RGB_RED_PIN >= 0) {
        digitalWrite(robot_config::TOP_RGB_RED_PIN, rgb_level(red));
    }
    if (robot_config::TOP_RGB_GREEN_PIN >= 0) {
        digitalWrite(robot_config::TOP_RGB_GREEN_PIN, rgb_level(green));
    }
    if (robot_config::TOP_RGB_BLUE_PIN >= 0) {
        digitalWrite(robot_config::TOP_RGB_BLUE_PIN, rgb_level(blue));
    }
}

void render_top_led() {
    if (!robot_config::ENABLE_TOP_RGB) {
        return;
    }

    if (robot_stopped()) {
        write_top_rgb(top_red_on, false, false);
        return;
    }

    top_red_on = true;
    write_top_rgb(true, false, false);
}

void update_top_led() {
    if (!robot_config::ENABLE_TOP_RGB) {
        return;
    }

    if (!robot_stopped()) {
        render_top_led();
        return;
    }

    const unsigned long now_ms = millis();
    if (now_ms - last_led_blink_ms < LED_BLINK_INTERVAL_MS) {
        return;
    }

    last_led_blink_ms = now_ms;
    top_red_on = !top_red_on;
    render_top_led();
}

void begin_top_led() {
    if (!robot_config::ENABLE_TOP_RGB) {
        return;
    }

    if (robot_config::TOP_RGB_RED_PIN >= 0) {
        pinMode(robot_config::TOP_RGB_RED_PIN, OUTPUT);
    }
    if (robot_config::TOP_RGB_GREEN_PIN >= 0) {
        pinMode(robot_config::TOP_RGB_GREEN_PIN, OUTPUT);
    }
    if (robot_config::TOP_RGB_BLUE_PIN >= 0) {
        pinMode(robot_config::TOP_RGB_BLUE_PIN, OUTPUT);
    }

    top_red_on = true;
    last_led_blink_ms = millis();
    render_top_led();
}

const char* wifi_status_name(int status) {
    switch (status) {
        case WL_IDLE_STATUS:
            return "idle";
        case WL_NO_SSID_AVAIL:
            return "no_ssid";
        case WL_SCAN_COMPLETED:
            return "scan_done";
        case WL_CONNECTED:
            return "connected";
        case WL_CONNECT_FAILED:
            return "connect_failed";
        case WL_CONNECTION_LOST:
            return "connection_lost";
        case WL_DISCONNECTED:
            return "disconnected";
        case WL_NO_MODULE:
            return "no_module";
        default:
            return "unknown";
    }
}

void stop_motors() {
    if (!motoron_ready) {
        return;
    }

    motoron.setSpeed(MOTOR_LEFT, 0);
    motoron.setSpeed(MOTOR_RIGHT, 0);
    motoron.setSpeed(MOTOR_AUX, 0);
}

void set_motor_speeds(int16_t left_speed, int16_t right_speed) {
    if (!motoron_ready) {
        return;
    }

    motoron.setSpeed(MOTOR_LEFT, left_speed);
    motoron.setSpeed(MOTOR_RIGHT, right_speed);
    motoron.setSpeed(MOTOR_AUX, 0);

    if (motoron.getLastError() != 0) {
        motoron_ready = false;
        Serial.print("motoron_error=");
        Serial.println(motoron.getLastError());
    }
}

void apply_motor_state() {
    if (robot_stopped()) {
        stop_motors();
    } else {
        set_motor_speeds(RUN_SPEED, trim_right_speed(RUN_SPEED));
    }
    render_top_led();
}

void configure_motor(uint8_t motor) {
    motoron.setMaxAcceleration(motor, MOTOR_ACCEL);
    motoron.setMaxDeceleration(motor, MOTOR_DECEL);
}

void begin_motoron() {
    Serial.println("Motoron: starting Wire1");
    Wire1.begin();
    Wire1.setClock(100000);

    motoron.setBus(&Wire1);
    motoron.reinitialize();
    delay(10);
    motoron.disableCrc();
    delay(10);
    motoron.clearResetFlag();
    motoron.clearMotorFaultUnconditional();
    motoron.setCommandTimeoutMilliseconds(2000);
    configure_motor(MOTOR_LEFT);
    configure_motor(MOTOR_RIGHT);
    configure_motor(MOTOR_AUX);

    motoron_ready = motoron.getLastError() == 0;
    Serial.print("motoron_ready=");
    Serial.print(motoron_ready ? 1 : 0);
    Serial.print(" error=");
    Serial.println(motoron.getLastError());
    stop_motors();
}

void print_stop_state(const char* reason) {
    Serial.print("state=");
    Serial.print(robot_stopped() ? "STOPPED" : "RUNNING");
    Serial.print(" button_stop=");
    Serial.print(stopped_by_button ? 1 : 0);
    Serial.print(" mqtt_stop=");
    Serial.print(stopped_by_server ? 1 : 0);
    Serial.print(" reason=");
    Serial.println(reason);
}

void set_button_stopped(bool stopped, const char* reason) {
    if (stopped_by_button == stopped) {
        return;
    }

    stopped_by_button = stopped;
    apply_motor_state();
    print_stop_state(reason);
}
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

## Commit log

2026-05-13 Add main CAD link to main_cad_link file
2026-05-19 Fixed errors + added revive button
    [LED_and_Button.ino]
2026-05-20 Button sensitivity fix and adjustment for proper set up
    [LED_and_Button.ino]
2026-05-26 all sensors minus the distance sensors
    can turn reliably with lines needs walls though for parts of map without lines
2026-05-28 Refactor line sensor functions for clarity and efficiency
2026-06-02 Create Cad
2026-06-04 Add final viva/test run log documentation
    Documented the final test run log for the robot, detailing various tests conducted including startup calibration, line following, IMU turning, RFID detection, obstacle avoidance, tunnel/wall following, and seed dispensing.
